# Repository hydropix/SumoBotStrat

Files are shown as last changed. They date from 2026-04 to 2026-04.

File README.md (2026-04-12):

# SumoBotStrat

Un robot sumo autonome qui se bat tout seul sur un ring ! Il detecte son adversaire, le poursuit et essaie de le pousser hors de l'arene. Toute sa strategie a ete mise au point grace a un simulateur sur ordinateur, puis transferee sur le vrai robot.

SumoBot MuJoCo simulation

## C'est quoi un robot sumo ?

Le robot sumo, c'est un sport de robots : deux robots sont poses sur un ring circulaire noir (appele "dohyo"), et chacun doit pousser l'autre en dehors. Le ring a une bordure blanche que le robot doit detecter pour ne pas tomber lui-meme.

Notre robot pese entre 500g et 1kg et fonctionne avec une carte **Arduino Mega 2560** (une sorte de mini-ordinateur programmable).

## Notre approche : simuler avant de construire

Plutot que de programmer le robot a l'aveugle et de faire des dizaines d'essais physiques (ce qui prend du temps et casse le materiel), on a choisi une approche differente :

**1. On a cree un simulateur sur ordinateur** qui reproduit fidelement le comportement du robot : ses moteurs, ses capteurs, la physique des collisions, le ring...

**2. On a fait jouer le robot virtuel des milliers de matchs** contre differents types d'adversaires pour trouver les meilleurs reglages.

**3. On a transfere la strategie gagnante sur le vrai robot.**

```text
    ORDINATEUR                                         ROBOT REEL
 ┌──────────────┐     ┌──────────────┐     ┌──────────────────────┐
 │  Simulateur  │ --> │ Optimisation │ --> │  Code Arduino final  │
 │  (virtuel)   │     │ (des milliers│     │  (memes reglages)    │
 │              │     │  de matchs)  │     │                      │
 └──────────────┘     └──────────────┘     └──────────────────────┘
```

## Le simulateur

Le simulateur est un programme qui fait "comme si" le robot existait dans l'ordinateur. Il calcule tout : comment les roues tournent, comment le robot glisse sur le sol, ce que voient les capteurs...

Vous pouvez l'essayer directement dans votre navigateur :

**[Lancer le simulateur](https://hydropix.github.io/SumoBotStrat/simulation/index.html)** (cliquez pour essayer !)

Dans le simulateur, vous verrez :
- Le ring noir avec sa bordure blanche
- Notre robot (en bleu) qui tourne, cherche, et attaque
- Un adversaire (en rouge) qu'on peut controler
- Les faisceaux laser qui detectent l'ennemi
- L'etat actuel du robot (recherche, poursuite, charge, esquive...)

### La regle d'or : pas de triche !

Le robot dans le simulateur n'a le droit d'utiliser **que** les informations qu'il aurait en vrai :
- Ses 3 capteurs laser pour "voir" l'adversaire (portee ~80 cm)
- Ses 3 capteurs de ligne pour detecter le bord du ring
- Son accelerometre/gyroscope pour sentir les chocs et sa rotation

Il n'a **pas le droit** de connaitre sa position exacte sur le ring, ni la position de l'ennemi. Comme ca, ce qui marche en simulation marchera aussi en vrai !

### Deux simulateurs complementaires

Le projet contient en fait **deux systemes de simulation** qui partagent la meme regle capteurs-uniquement :

**1. Simulateur JavaScript ([simulation/](simulation/))** — Simulation 2D legere (HTML + Canvas, zero dependance). C'est le simulateur utilise pour l'optimisation Monte Carlo massive et l'iteration rapide sur la strategie. Il tourne dans le navigateur ou en batch Node.js via [headless.js](simulation/headless.js) et [montecarlo.js](simulation/montecarlo.js).

**2. Simulateur MuJoCo ([simulation/mujoco/](simulation/mujoco/))** — Simulation physique 3D haute fidelite basee sur [MuJoCo](https://mujoco.org/) (Python). Permet de valider la strategie sur une physique rigide realiste (collisions, frottements, inertie 3D) avant le portage sur Arduino. Le GIF en haut du README montre ce simulateur en action.

Structure du simulateur MuJoCo :
- [models/](simulation/mujoco/models/) — modeles XML MuJoCo (arene, bot, ennemi, scene)
- [physics/](simulation/mujoco/physics/) — moteur de simulation et modele moteur N20
- [sensors/](simulation/mujoco/sensors/) — capteurs simules (ligne TCRT5000, laser VL53L0X, IMU MPU6050)
- [ai/](simulation/mujoco/ai/) — `bot_ai.py`, `enemy_ai.py`, parametres de strategie
- [runners/](simulation/mujoco/runners/) — `viewer.py` (interactif 3D), `headless.py` (batch), `montecarlo.py`

Installation et lancement du simulateur MuJoCo :

```bash
cd simulation/mujoco
setup.bat              # cree venv + installe mujoco, numpy
run_viewer.bat         # viewer 3D interactif
run_headless.bat       # batch de matchs headless
run_montecarlo.bat     # optimisation des parametres
```

## Comment on a trouve les meilleurs reglages : la methode Monte Carlo

Le robot a 16 reglages qu'on peut ajuster : a quelle vitesse il tourne pour chercher, a quelle vitesse il charge, a quel angle il attaque de cote, etc. Trouver la meilleure combinaison a la main serait impossible (il y a des milliards de possibilites).

On a donc utilise la **methode Monte Carlo** : c'est une technique qui consiste a essayer beaucoup de combinaisons au hasard et garder les meilleures. C'est un peu comme si vous lanciez des flechettes au hasard sur une cible, et qu'a chaque tour vous vous rapprochiez de la zone ou tombent les meilleures flechettes.

### Etape 1 — Chercher large

On genere **80 combinaisons de reglages** au hasard, et chacune joue **200 matchs** contre **12 adversaires differents** :
- Des adversaires de toutes tailles (petits, gros, legers, lourds, lents, rapides)
- Des adversaires "intelligents" qui traquent aussi notre robot

On garde les 8 meilleures combinaisons et on les reteste avec 800 matchs pour etre sur.

### Etape 2 — Affiner

Autour de la meilleure combinaison de l'etape 1, on genere **100 nouvelles combinaisons** proches (on ajuste legerement chaque reglage). On les reteste et on garde la meilleure.

### Etape 3 — Valider

On fait jouer le champion **3000 matchs** contre chaque type d'adversaire pour confirmer qu'il est vraiment bon partout.

### Resultats

| Adversaire | Victoires |
| --- | --- |
| Adversaires basiques (8 types differents) | 99.7 a 100% |
| Adversaire intelligent (standard) | 92.5% |
| Adversaire intelligent + lourd + rapide | ~47% |

Le seul adversaire problematique est un ennemi a la fois intelligent, lourd et rapide. En competition reelle, ce scenario est tres rare.

## Comment le robot "reflechit" : la machine a etats

Le robot ne "pense" pas vraiment, mais il suit des regles precises. A chaque instant, il est dans un **etat** (une situation) et reagit en fonction de ce qu'il detecte. Voici ses 8 etats :

| Etat | Ce que fait le robot | Quand ? |
| ---- | --- | --- |
| **WAIT_START** | Attend qu'on appuie sur le bouton | Au demarrage |
| **COUNTDOWN** | Attend 5 secondes (reglementaire) | Apres le bouton |
| **SEARCH** | Tourne sur lui-meme pour scanner autour | Quand il ne voit rien |
| **FLANK** | Approche en arc de cercle (~30 deg) | Ennemi detecte mais loin (> 63 cm) |
| **TRACK** | Suit l'ennemi en ajustant sa direction | Ennemi detecte a moyenne distance |
| **CHARGE** | Fonce a pleine puissance ! | Ennemi proche (< 37 cm) |
| **EVADE** | Recule et tourne | Bord du ring detecte |
| **CENTER** | Avance tout droit pour revenir au centre | Apres une esquive |

En plus, le robot reagit aux chocs grace a son accelerometre :
- **Souleve par l'adversaire** : il recule et tourne pour se degager
- **Frappe sur le cote** : il tourne vers l'attaquant pour riposter
- **Frappe de face** : il esquive lateralement

## Ce qu'on a decouvert grace a la simulation

La simulation nous a permis de tester des idees et de garder seulement ce qui marche. Voici les decouvertes les plus importantes :

- **Les capteurs laser a 30 deg, c'est mieux que 90 deg.** On a teste avec les capteurs lateraux pointes a 90 degres (sur les cotes), mais le robot perdait trop souvent la cible. A 30 degres, il a un champ de vision plus concentre vers l'avant et gagne **8% de matchs en plus**.

- **Pousser meme au bord du ring, ca marche.** Normalement le robot recule quand il detecte le bord. Mais si l'ennemi est juste devant, on le laisse continuer a pousser. Ca reduit les matchs nuls de 26% a 13%.

- **Un controleur simple est meilleur qu'un controleur complique.** On a essaye un systeme de direction plus avance (controleur PD), mais le robot oscillait dans tous les sens. Le controleur simple (P) est stable et efficace.

## Les fichiers du projet

| Dossier | Contenu |
| --- | --- |
| `simulation/` | Le simulateur (ouvrir `index.html` dans un navigateur) |
| `simulation/montecarlo_v3.js` | Le programme d'optimisation Monte Carlo |
| `sumo_strategy/` | Le code final pour l'Arduino (le "cerveau" du robot) |
| `test_moteur1/` | Programme de test pour 1 moteur |
| `test_2moteurs/` | Programme de test pour 2 moteurs |
| `test_capteur_ligne/` | Programme de test pour les capteurs de bord |
| `test_ligne_moteurs/` | Programme de test : capteurs + moteurs ensemble |
| `docs/` | Schemas electriques et [guide de montage](docs/HARDWARE.md) |

## Essayer le simulateur

Ouvrir le lien ci-dessous dans un navigateur (Chrome, Firefox, Edge...). Rien a installer !

**[Lancer le simulateur](https://hydropix.github.io/SumoBotStrat/simulation/index.html)**

## Programmer le vrai robot

1. Installer [Arduino IDE](https://www.arduino.cc/en/software) sur votre ordinateur
2. Brancher l'Arduino Mega en USB
3. Ouvrir le fichier `sumo_strategy/sumo_strategy.ino`
4. Cliquer sur la fleche "Upload" pour envoyer le code sur le robot
5. Appuyer sur le bouton START du robot pour lancer le match !

## Construire le robot

Voir le **[guide de montage complet](docs/HARDWARE.md)** pour la liste des pieces et les instructions de cablage pas-a-pas.

## Licence

Voir [LICENSE](LICENSE).

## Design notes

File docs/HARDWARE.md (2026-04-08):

# Guide de montage du robot

Ce guide explique comment assembler le robot sumo pas a pas. Chaque etape est testable individuellement : on branche, on teste, et on passe a la suite seulement quand ca marche.

## De quoi a-t-on besoin ?

### Les composants principaux

| Piece | C'est quoi ? | Combien ? |
| ----- | --- | --- |
| Arduino Mega 2560 | Le "cerveau" du robot. C'est un mini-ordinateur qu'on peut programmer | 1 |
| Sensor Shield Mega | Une carte qui se branche sur l'Arduino pour faciliter le branchement des capteurs | 1 |
| L298N | Un module qui permet a l'Arduino de controler les moteurs (l'Arduino seule n'est pas assez puissante) | 1 |
| Moteurs N20 12V 500RPM | Petits moteurs avec reducteur, ils font tourner les roues | 2 |
| Roues silicone | Roues en silicone qui accrochent bien sur le ring | 2 |
| Bille folle | Une petite roulette qui sert de 3eme point d'appui a l'arriere | 1 |
| VL53L0X | Capteurs laser qui mesurent la distance (pour "voir" l'adversaire) | 3 |
| TCRT5000 | Capteurs infrarouge qui detectent la couleur du sol (noir = ring, blanc = bord) | 3 |
| MPU6050 | Capteur qui detecte les mouvements, chocs et rotations du robot | 1 |
| Batterie NiMH 7.2V | La batterie rechargeable qui alimente tout | 1 |
| Module LM2596 | Un convertisseur qui transforme le 7.2V de la batterie en 5V pour l'Arduino | 1 |
| Bouton poussoir | Pour demarrer le match | 1 |
| Fils Dupont et connecteurs | Pour relier tous les composants entre eux | - |

### Les outils necessaires

- Un tournevis cruciforme (petit)
- Un multimetre (pour verifier les tensions)
- Arduino IDE installe sur un ordinateur (logiciel gratuit)
- Un cable USB pour brancher l'Arduino a l'ordinateur

## Vocabulaire utile

Avant de commencer, voici quelques mots qu'on va utiliser souvent :

| Mot | Signification |
| --- | --- |
| **GND** | La masse, c'est le "-" de l'alimentation. Comme le pole negatif d'une pile |
| **VCC** ou **5V** | L'alimentation positive a 5 volts |
| **Pin** | Une broche (patte metallique) sur l'Arduino ou un composant |
| **PWM** | Un signal qui permet de controler la vitesse d'un moteur (au lieu de juste "allume/eteint") |
| **I2C** | Un "langage" que les capteurs utilisent pour parler a l'Arduino a travers 2 fils (SDA et SCL) |
| **Shield** | Une carte qui s'empile sur l'Arduino pour ajouter des fonctions |
| **Serial Monitor** | Un ecran dans Arduino IDE qui affiche les messages du robot (utile pour le debug) |

## Etape 1 — L'alimentation (le courant electrique)

C'est la premiere chose a faire : s'assurer que tout est bien alimente.

### Le probleme

La batterie donne 7.2V, mais l'Arduino et les capteurs ont besoin de 5V. Si on branche 7.2V directement, on grille tout ! Il faut donc un convertisseur (le module LM2596) qui transforme le 7.2V en 5V.

### Branchement de l'alimentation

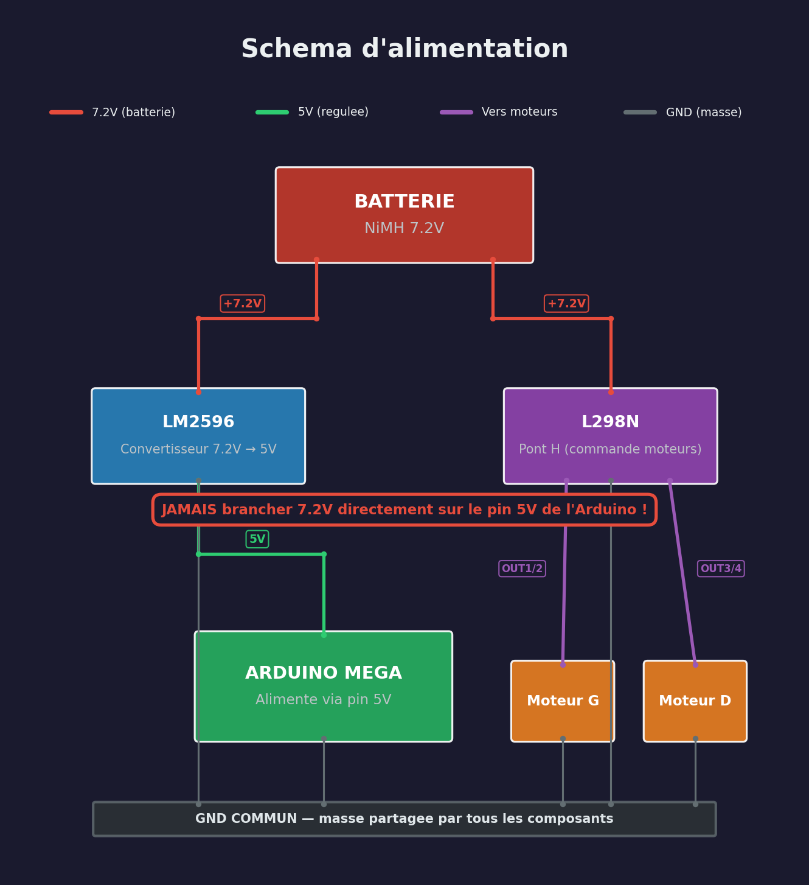
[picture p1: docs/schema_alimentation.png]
Schema d'alimentation


### Comment regler le LM2596

1. Brancher la batterie sur les bornes Vin (+) et Vin (-) du LM2596
2. **Ne rien brancher sur la sortie pour l'instant**
3. Mettre le multimetre sur la sortie (Vout + et Vout -)
4. Tourner la petite vis (potentiometre) avec un tournevis jusqu'a lire **5.0V**
5. Seulement maintenant, brancher la sortie sur le pin 5V de l'Arduino

> **ATTENTION** : Ne JAMAIS brancher la batterie 7.2V directement sur le pin 5V de l'Arduino. Ca le detruit immediatement et c'est irreversible.

### Verification

Brancher la batterie. L'Arduino doit s'allumer (une petite LED verte s'allume sur la carte). Si rien ne se passe, verifier les branchements et la tension du LM2596.

## Etape 2 — Les moteurs

Les moteurs font avancer et tourner le robot. On en utilise 2 : un a gauche et un a droite. En les faisant tourner a des vitesses differentes, le robot peut tourner.

### Le role du L298N

L'Arduino ne peut pas alimenter les moteurs directement (pas assez de puissance). Le module L298N sert d'intermediaire : l'Arduino lui envoie des ordres ("tourne a gauche, vitesse 50%"), et le L298N transmet la puissance de la batterie aux moteurs.

### Branchement des moteurs

```text
L298N                    Arduino Mega
─────                    ────────────
ENA ──────────────────── Pin 10     (vitesse moteur gauche)
IN1 ──────────────────── Pin 9      (sens moteur gauche)
IN2 ──────────────────── Pin 8      (sens moteur gauche)
IN3 ──────────────────── Pin 6      (sens moteur droit)
IN4 ──────────────────── Pin 7      (sens moteur droit)
ENB ──────────────────── Pin 5      (vitesse moteur droit)
GND ──────────────────── GND

L298N                    Moteurs
─────                    ───────
OUT1, OUT2 ──────────── Moteur GAUCHE (les 2 fils du moteur)
OUT3, OUT4 ──────────── Moteur DROIT  (les 2 fils du moteur)
```

### Le jumper 5V du L298N

Il y a un petit cavalier (jumper) sur le L298N marque "5V EN". **Il faut l'enlever.** Ce jumper active un regulateur interne qui n'est pas assez puissant pour notre robot. On utilise le LM2596 a la place.

### Si un moteur tourne a l'envers

Pas de panique ! Il suffit d'inverser les 2 fils du moteur sur le bornier du L298N (echanger OUT1 et OUT2, ou OUT3 et OUT4).

### Test

1. Brancher l'Arduino a l'ordinateur en USB
2. Ouvrir `test_moteur1/test_moteur1.ino` dans Arduino IDE
3. Cliquer sur "Upload" (fleche vers la droite)
4. Le moteur gauche doit tourner dans un sens, puis dans l'autre
5. Ensuite, tester avec `test_2moteurs/test_2moteurs.ino` : les deux moteurs tournent ensemble (avant, arriere, tourne a gauche, tourne a droite)

## Etape 3 — Les capteurs de ligne (TCRT5000)

Ces capteurs empechent le robot de tomber du ring. Ils envoient un faisceau infrarouge vers le sol et mesurent la lumiere reflechie. Le sol noir du ring reflechit peu, mais la bordure blanche reflechit beaucoup.

### Branchement des capteurs de ligne

On utilise le Shield Sensor, une carte qui se branche directement sur l'Arduino et qui offre des rangees de 3 broches (S, V, G) pour chaque pin :

- **S** = Signal (le fil de donnees du capteur)
- **V** = 5V (l'alimentation du capteur)
- **G** = GND (la masse)

```text
Shield Sensor Mega (section ANALOG)
────────────────────────────────────
Pin A0 (S/V/G) ──── TCRT5000 #1 (avant-gauche)
Pin A1 (S/V/G) ──── TCRT5000 #2 (avant-droit)
Pin A2 (S/V/G) ──── TCRT5000 #3 (arriere)
```

> **ATTENTION** : Le shield a deux zones qui se ressemblent. Les pins analogiques (A0, A1, A2...) sont d'un cote, et les pins numeriques de l'autre. Il faut brancher sur le cote **ANALOG**.

### Ou placer les capteurs sur le robot

Le placement de tous les capteurs est visible sur ce schema (vue de dessus) :

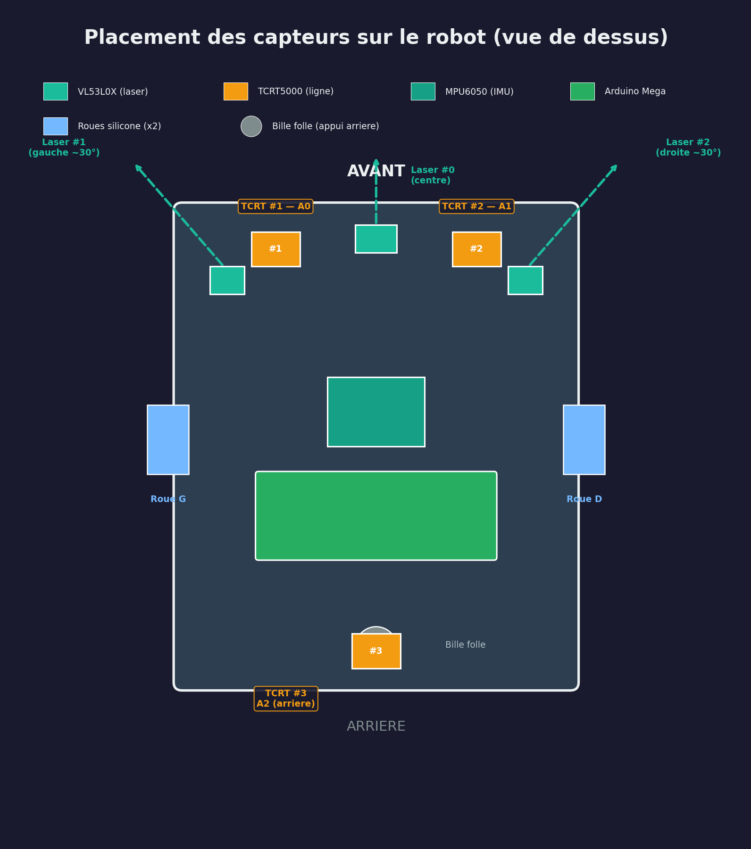
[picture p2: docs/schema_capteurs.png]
Placement des capteurs


Les 2 capteurs avant depassent du chassis vers l'avant, a 5mm du sol. Le capteur arriere est au milieu, a 5mm du sol aussi.

### Test et calibration

1. Ouvrir `test_capteur_ligne/test_capteur_ligne.ino` et l'envoyer sur l'Arduino
2. Ouvrir le Serial Monitor dans Arduino IDE (icone loupe en haut a droite, regler sur 9600 baud)
3. Presenter une feuille blanche sous le capteur : on doit voir une valeur basse (ex: 100-200)
4. Presenter une surface noire : la valeur doit etre haute (ex: 600-900)
5. Le seuil par defaut est 300. Si vos valeurs sont differentes, ajustez-le dans le code

Ensuite, tester avec `test_ligne_moteurs/test_ligne_moteurs.ino` : le robot doit avancer et reculer automatiquement quand il detecte du blanc.

## Etape 4 — Les capteurs de distance (VL53L0X)

Ce sont les "yeux" du robot. Ils envoient un faisceau laser invisible et mesurent le temps que met la lumiere a revenir, ce qui donne la distance d'un objet (ici, l'adversaire). Portee : environ 80 cm.

Le robot en utilise 3 : un qui regarde droit devant, et deux sur les cotes (a environ 30 degres). Ca lui donne un "champ de vision" de 60 degres.

### Le probleme : ils ont tous la meme adresse

Les VL53L0X communiquent avec l'Arduino par un systeme appele I2C (2 fils partages : SDA et SCL). Le probleme, c'est qu'ils ont tous la meme "adresse" par defaut. C'est comme si 3 eleves dans une classe avaient le meme prenom : quand le prof appelle, ils repondent tous en meme temps !

La solution : chaque capteur a un fil special (XSHUT) qui permet de l'allumer ou l'eteindre. Au demarrage, le code allume les capteurs un par un et donne a chacun une adresse differente.

### Branchement des lasers

```text
Les 3 VL53L0X partagent les memes fils I2C :
  VIN ──── 5V (via le shield)
  GND ──── GND
  SDA ──── Pin 20 (sur l'Arduino Mega, c'est le fil de donnees I2C)
  SCL ──── Pin 21 (c'est le fil d'horloge I2C)

Chaque capteur a son fil XSHUT individuel :
  VL53L0X #0 (centre) : XSHUT ──── Pin 22
  VL53L0X #1 (gauche) : XSHUT ──── Pin 23
  VL53L0X #2 (droite) : XSHUT ──── Pin 24
```

### Ou placer les capteurs laser

Le placement des lasers est visible sur le schema des capteurs plus haut. Le laser #0 pointe droit devant, les lasers #1 et #2 sont orientes a environ 30 degres de chaque cote.

> **Pourquoi 30 degres et pas plus ?** On a teste avec des angles de 60 et 90 degres dans le simulateur, mais le robot perdait la cible trop souvent. A 30 degres, il gagne 8% de matchs en plus !

### Test

Apres le branchement, envoyer le code principal (`sumo_strategy/sumo_strategy.ino`) et ouvrir le Serial Monitor. Au demarrage, le message "Lasers OK" doit apparaitre. Si vous voyez "ERR laser0" (ou 1 ou 2), verifier le cablage du capteur concerne.

## Etape 5 — L'accelerometre/gyroscope (MPU6050)

Ce capteur detecte les mouvements du robot : les chocs, les rotations, et meme si le robot est souleve par l'adversaire. C'est un peu comme l'oreille interne chez l'humain, qui nous donne le sens de l'equilibre.

### Branchement de l'IMU

Le MPU6050 partage les memes fils I2C que les capteurs laser (SDA et SCL), mais avec une adresse differente, donc pas de conflit.

```text
MPU6050              Arduino Mega
───────              ────────────
VCC ──────────────── 5V (via le shield)
GND ──────────────── GND
SDA ──────────────── Pin 20 (meme fil que les VL53L0X)
SCL ──────────────── Pin 21 (meme fil que les VL53L0X)
AD0 ──────────────── GND (ca fixe son adresse pour eviter les conflits)
```

### Ce que le robot en fait

| Mesure | Le robot l'utilise pour... |
| --- | --- |
| Acceleration avant/arriere | Detecter une collision frontale et esquiver sur le cote |
| Acceleration laterale | Detecter un choc sur le cote et tourner vers l'attaquant |
| Vitesse de rotation | Savoir quand il a fait un tour complet en mode recherche |

### Placement de l'IMU

Monter le MPU6050 **au centre du robot**, bien fixe. S'il vibre trop, les mesures seront fausses. Utiliser du scotch double-face epais ou de la mousse pour l'isoler des vibrations.

## Etape 6 — Le bouton de demarrage

En competition, on doit appuyer sur un bouton, puis le robot attend 5 secondes avant de commencer (c'est la regle). Ce bouton declenche le compte a rebours.

### Branchement du bouton

C'est le branchement le plus simple du projet :

```text
Bouton poussoir
  Broche 1 ──── Pin 2 de l'Arduino
  Broche 2 ──── GND
```

Pas besoin de resistance : l'Arduino a une resistance interne (pull-up) qui fait le travail.

### Comment ca marche

1. Robot allume → la LED de l'Arduino clignote **lentement** (il attend)
2. Appui sur le bouton → la LED clignote **vite** (compte a rebours de 5 secondes)
3. Fin du compte a rebours → le robot demarre et cherche l'ennemi

## Schema de cablage complet

Voici une vue d'ensemble de tous les branchements :

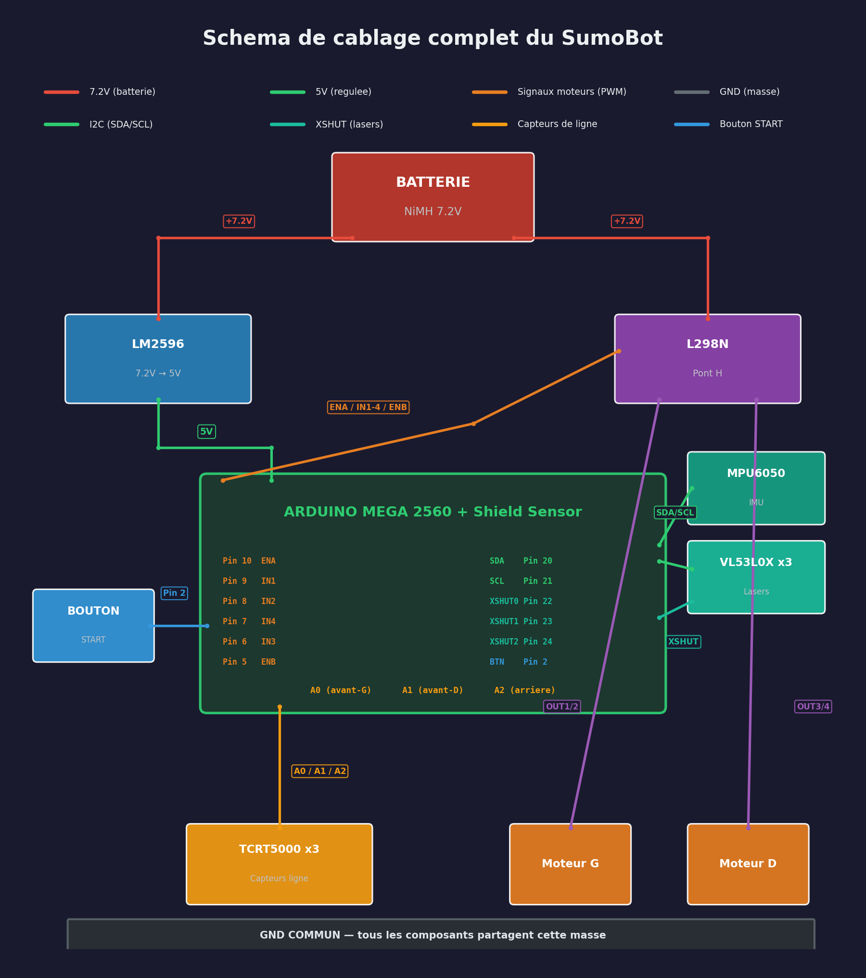
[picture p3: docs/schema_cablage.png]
Schema de cablage complet


## Tableau recapitulatif : quel fil va ou

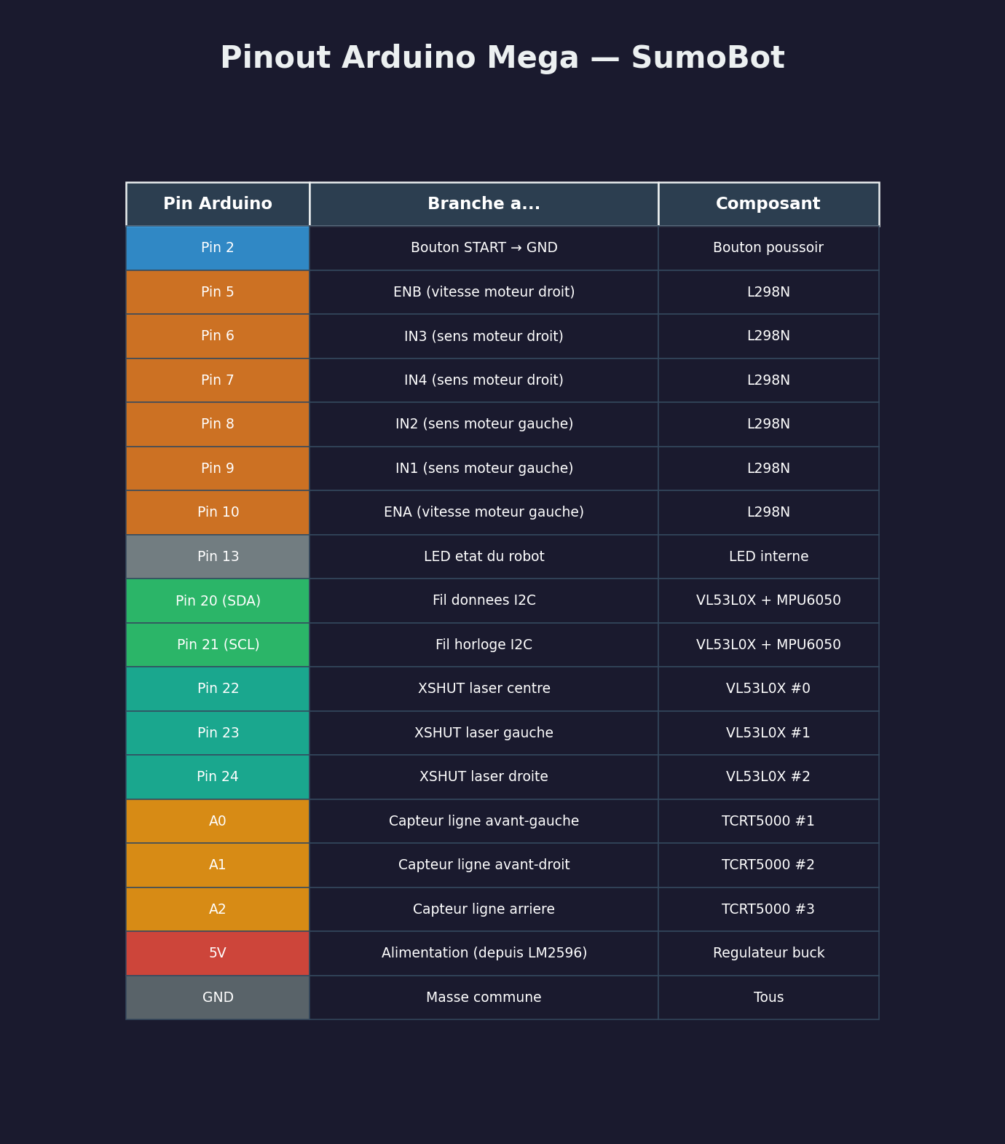
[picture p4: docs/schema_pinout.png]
Tableau du pinout


## Conseils importants

### La masse commune (GND)

C'est la cause numero 1 des problemes. **Tous les composants doivent partager le meme GND.** Si un seul GND est mal branche, les moteurs peuvent se comporter bizarrement, les capteurs peuvent donner des valeurs fausses, etc. En cas de probleme, verifier les GND en premier.

### Le poids

En competition, le robot doit peser moins de 1 kg. Voici une estimation du poids de chaque piece :

| Piece | Poids |
| ----- | ----- |
| Arduino Mega + shield | ~55g |
| L298N | ~30g |
| 2 moteurs N20 + roues | ~40g |
| Batterie NiMH 7.2V | ~150-200g |
| Chassis + lame | ~300-400g |
| Capteurs + cablage | ~50g |
| **Total** | **~625-775g** |

Il reste de la marge, mais attention au chassis : c'est souvent la piece la plus lourde.

### Les vibrations

Les capteurs laser (VL53L0X) et l'accelerometre (MPU6050) sont sensibles aux vibrations. Si le robot vibre beaucoup en roulant, les mesures seront bruitees. Utiliser de la mousse ou du scotch double-face epais entre les capteurs et le chassis.

### Les fils I2C

Le bus I2C (les fils SDA et SCL) est partage entre 4 capteurs. Pour que ca marche bien :

- Garder les fils **courts** (moins de 15 cm)
- Si les capteurs se deconnectent souvent, ajouter une resistance de 4.7 kohms entre SDA et 5V, et une autre entre SCL et 5V (certains modules les ont deja)
- Le code a un systeme de recuperation automatique si le bus se bloque

### Le watchdog

Le code du robot active un "chien de garde" (watchdog). Si le programme se bloque pendant plus de 0.5 seconde, l'Arduino redemarre automatiquement. C'est une securite pour que le robot ne reste jamais immobile en plein match.

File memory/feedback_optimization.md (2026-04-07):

---
name: Strategy Optimization Results - What Works and What Doesn't
description: Detailed log of all tested strategies and parameter changes with measured impact - prevents re-testing failed approaches
type: feedback
---

## POSITIF (garder, ne pas reverter)

### 3 lasers avant (centre + 2 lateraux en V) — IMPACT MAJEUR
- Ancien: 2 lasers a ±0.26 rad, kp=0.6 → 86.9% pondere multi-taille
- Nouveau: 3 lasers (centre droit + lateraux ±0.47 rad), kp=1.28 → **95.1% pondere** (+8.2%)
- Le laser central comble le trou entre les lateraux. Quand il detecte mais pas un lateral, sa distance + centerFill (165mm) remplace le lateral manquant.
- Avec le centre, on peut aller a ±27° sans degradation (ancien max etait ±17° sans centre).
- Robustesse multi-taille : S(35mm)=94.4%, D(55mm)=95.2%, XL(75mm)=95.3%. L'ancien s'effondrait a 78% sur XL.
- Monte Carlo v2 confirme: kp=0.6-1.3, laserAngle=0.40-0.48, centerFill=140-280 sont tous au plafond (94-95%).

### Edge-charge (ne pas EVADE sur 1 seul capteur avant pendant CHARGE) — IMPACT MAJEUR
- **+2-3% WR, timeouts /2** (de 26% a ~13%)
- Logique: si CHARGE/TRACK actif + ennemi detecte devant + 1 seul capteur avant sur la ligne → continuer a pousser avec correction de direction (edgeSteer).
- EVADE seulement si: les 2 capteurs avant sont dans le blanc, OU capteur arriere, OU pas en engagement.
- edgeSteer: 0.3/0.5/0.7 donnent des resultats quasi identiques. Le facteur cle est de NE PAS declencher EVADE.

### searchPwm=0.95 — impact modere
- +1% WR vs 0.75. Spin plus rapide = balayage plus rapide.
- 1.0 ne fait pas mieux que 0.95.

### trackPwm=0.9 — impact modere
- +1% WR vs 0.8. Ferme la distance plus vite.
- 0.95 est trop agressif (leger recul).

### evadePwm=0.85 — impact leger
- Reduit timeouts de ~2%. Evade plus rapide = retour au combat plus vite.

## NEGATIF (ne PAS re-tester)

### Capteurs lateraux a 90° — TOUJOURS NEGATIF
Teste sous 5 formes differentes, toutes pires que baseline:
1. **PIVOT state (spin pur vers detection laterale)** : 78.2% WR. Le bot oscille entre PIVOT et SEARCH.
2. **Direction hint continu** : 79.7% WR. Les lateraux detectent presque toujours (800mm portee, arene 385mm rayon) → flip-flop constant.
3. **Single-shot hint (1ere frame seulement)** : 88.2% WR. Neutre vs baseline.
4. **Close-range acquire (<250mm)** : 80.9% WR. ACQUIRE bloquant.
5. **Curved flank approach** : 83.4% WR. Toujours du drift parasite.
**Why:** Dans une arene de 77cm, le temps de rotation 90° pour face-to-face est trop long — l'ennemi bouge pendant le pivot. La portee 800mm cause des detections perpetuelles.

### Arc search (forward + spin au centre) — NEGATIF
- Derive hors portee laser. Le bot s'eloigne de la zone optimale.
- Teste avec fwdBias de 0.2 et 0.3: toujours pire.

### PD controller (ajout de kd) — CATASTROPHIQUE
- Amplifie le bruit laser → instabilite totale.

### Last-known direction search — NEUTRE
- La direction est perimee apres EVADE (le heading change). 89.6% vs 89.1% baseline = bruit statistique.

### Search direction reversal (inverser tous les 2-2.5s) — NEGATIF
- Empeche de completer un sweep complet. Combiné avec d'autres: toujours pire.

### Progressive speed ramp — NEUTRE/NEGATIF
- Perte tracking a mi-distance.

### chargePwm < 1.0 — TOUJOURS NEGATIF
- Force brute > precision en charge.

### chargeThreshold=300 — NEUTRE
- 88.4% vs 89.1% baseline. Pas de gain significatif.

### evade times plus courts (0.35/0.25) — NEGATIF
- 88.3% WR. Le bot ne recule pas assez loin du bord.

## Monte Carlo (150 configs, revalidation top 10 a 3000 rounds)
- Confirme que la config manuelle (kp=0.6, searchPwm=0.95, trackPwm=0.9, evadePwm=0.85, laserAngle=0.26) est au plafond.
- Aucune config random n'a battu le manual a 5000 rounds.
- Les parametres sont robustes: des configs tres differentes (kp 0.33-0.97) donnent toutes 93-95%.
- **Conclusion: c'est l'algo (edge-charge, laser V) qui drive la performance, pas le fine-tuning.**

**How to apply:** Avant de tester un changement, verifier ici qu'il n'a pas deja ete teste. Pour aller au-dela de 95%, il faut un changement structurel (nouveau capteur, nouvelle logique), pas du tuning.

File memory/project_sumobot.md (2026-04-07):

---
name: SumoBot Hardware Config & Progress
description: Arduino Mega sumo bot - hardware, wiring, pin assignments, build phases, simulation and current progress
type: project
---

Projet de robot sumo sur Arduino Mega 2560.

## Hardware

- Moteurs: N20 12V 500RPM x2 (alimentes a 7.5V via batterie)
- Driver: L298N (jumper auto-alimentation active)
- Batterie: NiMH 7.5V
- Masse cible: ~500g
- Capteurs ligne: TCRT5000 x3 (2 avant coins + 1 arriere centre)
- Capteurs distance: VL53L0X x4 disponibles, 3 montes a l'avant (1 centre droit + 2 lateraux ±27°), 1 en spare
- IMU: MPU6050 (prevu, pas encore monte). Adresse I2C 0x68, partage bus avec VL53L0X. INT sur pin 2 ou 3.
- Buck converter: LM2596 (7.5V -> 5V)
- Shield sensor Mega (rangees S/V/G par pin)

## Pin Assignments

- ENA (PWM) -> Pin 10, IN1 -> Pin 9, IN2 -> Pin 8 (moteur gauche)
- ENB (PWM) -> Pin 5, IN3 -> Pin 6, IN4 -> Pin 7 (moteur droit)
- TCRT5000 #1 -> A0, #2 -> A1, #3 -> A2
- VL53L0X: SDA -> Pin 20, SCL -> Pin 21, XSHUT -> Pins 22, 23, 24
- MPU6050: SDA -> Pin 20, SCL -> Pin 21 (partage I2C), INT -> Pin 2

## Alimentation

- 7.5V direct -> L298N VCC -> moteurs (jumper auto-alim)
- 7.5V -> Buck -> 5V -> Arduino pin 5V (PAS VIN), capteurs, lasers
- GND commun partout

## Simulation — Ce que le systeme modelise

### Fichiers

- simulation/index.html : simulateur visuel (HTML + JS Canvas, zero dependance)
- simulation/headless.js : simulateur headless Node.js pour tests massifs
- simulation/montecarlo.js : optimisation Monte Carlo v1 (2 lasers, obsolete)
- simulation/montecarlo_v2.js : Monte Carlo v2, multi-profil ennemi (taille/masse/vitesse)

### Physique (identique headless et html)

- **Moteurs N20** : modele force-vitesse lineaire, couple stall 0.025 N.m, 312 RPM a vide a 7.5V
- **Traction per-wheel** : mu=0.6, chaque roue a sa propre limite de traction. Stall force 1.63N > traction 1.47N = patinage a plein regime
- **Masse/vitesse per-robot** : chaque robot a ses propres mass, inertia, stallForce, noLoadSpeed, tractionMax
- **Collision** : impulsions avec restitution 0.15, masses individuelles
- **Tilt per-wheel (soulevement directionnel)** :
  - Continu tant que l'attaquant pousse (base sur vitesse de fermeture + force moteur, pas juste l'impact)
  - Direction: cote = souleve la roue du cote impacte. Arriere = les 2 roues. Face a face = pas de tilt (lames s'opposent)
  - Effet: traction de la roue soulevee chute (x1.8 par rad de tilt), la roue au sol garde sa traction → le bot pivote
  - Decay: 3.0 rad/s (~0.23s pour retomber completement)
  - Perspective visuelle: cote souleve = plus grand (plus proche camera), cote au sol = plus petit, trapeze
- **Friction laterale** : forte (30 s⁻¹), empeche le derapage lateral. Reduite par le tilt.
- **Sub-stepping** : physique a 240Hz, IA a 60Hz

### Capteurs simules

- **3x VL53L0X avant** : 1 centre (0°) + 2 lateraux (±27°). Raycasting sur le cercle de collision ennemi. Portee 800mm.
- **centerFill** : si centre detecte mais pas un lateral, d0 + 165mm remplace le lateral manquant.
- **3x TCRT5000 ligne** : detection du bord blanc (2 avant coins, 1 arriere centre)
- **IMU (MPU6050) simule** :
  - Accelerometre (ax, ay) : calcule depuis delta vitesse dans le referentiel robot, en m/s²
  - Gyroscope (gz) : omega du robot en rad/s. Heading cumule par integration.
  - Tilt : lu depuis tiltL/tiltR du modele physique

### Ennemi

- **Basic** : 5 comportements aleatoires (WANDER, ORBIT, AGGRESSIVE, DODGE, ZIGZAG) a 85% PWM
- **Smart** (--smart / touche S) : omniscient, 8 tactiques (FLANK, MATADOR, RUSH, SHADOW, EDGE_TRAP, JUKE, BULL, EXPLOIT_EVADE). Scoring pondere + 30% randomness. Realisme humain: bruit steering ±6°, vitesse 82-100%, 12% hesitation.
- **Taille variable** (touche V) : taille 35-75mm, masse 0.3-0.8kg, vitesse 70-130% randomises a chaque round
- L'ennemi subit aussi le tilt (il peut etre souleve par le bot)

### IA du bot — Machine a etats

SEARCH → TRACK → CHARGE (+ EVADE prioritaire sauf edge-charge)
Apres EVADE → CENTER (retour centre 0.35s) → SEARCH
Etats IMU: TILT_ESC (recul si tilt >14°), IMPACT (spin vers source si choc lateral >1.5g)
Heading search: apres 360° de spin sans detection, deplacement vers le centre

### Config actuelle

```text
kp=1.0  laserAngle=0.47  centerFill=165  searchPwm=0.954
trackPwm=1.0  evadePwm=1.0  edgeSteer=0.245  chargeThreshold=300
centerReturnTime=0.35
```

## Resultats

- **91.2% pondere multi-profil** vs basic (3000 rounds, 8 profils taille/masse/vitesse)
- **74.6%** vs smart enemy avec IMU+tilt (+1.8% vs sans IMU)
- Pertes FLANK reduites de 18% grace a IMU (detection impact lateral)
- Contre ennemi 0.8kg+130% vitesse (~2x momentum): WR plafonne a ~67% (limite physique)

## Faiblesses restantes

1. **EDGE_TRAP (~60% des pertes vs smart)**: ennemi entre bot et centre, gagne au timeout
2. **Attaques hors-cone (~30%)**: RUSH/FLANK depuis angles morts, partiellement resolu par IMU
3. Pas de capteur arriere (VL53L0X spare disponible)
4. Pas de capteurs ligne lateraux

### Pistes d'amelioration

- VL53L0X arriere (spare dispo, cout 0) → elimine angle mort arriere
- 2x TCRT5000 lateraux → survie edge-trap
- Ne pas charger quand heading pointe vers l'exterieur pres du bord
- Mode "hold center" si match > 15s
- 2x IR LED+phototransistor flancs (detection laterale rapide)

## Progression (2026-04-07)

- Phase 0-2: OK - Alimentation, Arduino, moteurs testes
- Phase 3: EN COURS - capteurs ligne et distance
- Phase 4: A faire - integration strategie sumo sur Arduino
- Simulation visuelle + headless: DONE
- Monte Carlo v1 + v2: DONE
- 3e laser central: DONE
- Tilt per-wheel + IMU simule: DONE
- Physique per-robot (masse/vitesse/taille variable): DONE
- Smart enemy: DONE
- CENTER_RETURN: DONE

**Why:** Projet personnel de competition sumo bot, categorie 500g-1kg.
**How to apply:** Utiliser smart enemy + taille variable pour guider les ameliorations capteurs/algo, puis porter sur Arduino.

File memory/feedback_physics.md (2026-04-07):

---
name: Simulation physics integrity
description: Simulation must use honest sensor-only AI and real physics - no omniscient shortcuts
type: feedback
---

Le bot ne doit utiliser QUE les donnees de ses capteurs (lasers VL53L0X en mm, TCRT5000 ligne). Pas de triche avec atan2 vers l'ennemi ou acces direct a la position adverse.

**Why:** Bruno a detecte que le mode SEARCH utilisait atan2(ene.y - bot.y, ...) pour s'orienter — ce n'est pas realiste. Un vrai robot tourne a l'aveugle jusqu'a ce qu'un laser detecte quelque chose.

**How to apply:** En mode SEARCH, rotation a vitesse fixe (spin aveugle). Toute logique de centrage/tracking doit passer par les lectures laser d1/d2. Les VL53L0X donnent des distances en mm — utiliser cette unite dans l'IA.

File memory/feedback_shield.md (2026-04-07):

---
name: Shield Sensor Mega
description: User uses a Mega sensor shield - connect via S/V/G rows, analog pins for TCRT5000
type: feedback
---

Bruno utilise un shield sensor pour le Mega. Les capteurs se branchent sur les rangées S (signal) / V (VCC) / G (GND) du shield.

**Why:** Simplifie le câblage, pas besoin de breadboard ni fils Dupont séparés pour VCC/GND.
**How to apply:** Toujours indiquer la rangée du shield (ex: "rangée A0 du shield") plutôt que des branchements fils individuels.

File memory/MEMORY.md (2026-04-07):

- [SumoBot Config & Progress](project_sumobot.md) — Hardware, simulation, strategie IA optimisee (95.2% WR), prochaine etape: porter sur Arduino
- [Bruno Profile](user_bruno.md) — Builder profile, French speaker, methodical hardware approach
- [Shield Sensor](feedback_shield.md) — Uses Mega sensor shield, connect via S/V/G rows
- [Physics Model](feedback_physics.md) — Simulation must use real SI physics, no cheating (atan2 toward enemy), blind search only
- [Optimization Results](feedback_optimization.md) — Detailed log of ALL tested strategies: what works (laser V, edge-charge) and what fails (side sensors, arc search, PD, etc.)

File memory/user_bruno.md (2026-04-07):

---
name: Bruno - Sumo Bot Builder
description: User building an Arduino Mega sumo bot, hardware-focused with progressive build approach
type: user
---

Bruno construit un robot sumo Arduino Mega. Approche méthodique et progressive (phase par phase). Documentation détaillée de son hardware et câblage. Communication en français.

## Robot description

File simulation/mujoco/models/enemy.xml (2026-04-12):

<mujoco model="enemy">
  <!--
    Enemy robot: same dimensions as sumobot by default.
    Configurable mass, size, speed via scene assembly.
  -->

  <default>
    <joint damping="0.0001" armature="0.00001"/>
    <geom condim="4" solimp="0.95 0.99 0.001" solref="0.004 1"/>
  </default>

  <asset>
    <material name="enemy_red" rgba="0.75 0.2 0.2 1"/>
    <material name="enemy_wedge" rgba="0.6 0.15 0.15 1"/>
    <material name="enemy_wheel" rgba="0.15 0.15 0.15 1"/>
  </asset>

  <worldbody>
    <body name="ene_chassis" pos="0 0 0.065">
      <freejoint name="ene_root"/>

      <inertial pos="-0.005 0 -0.003" mass="0.47" diaginertia="0.000396 0.000396 0.000784"/>

      <geom name="ene_body" type="box" size="0.05 0.05 0.0125" material="enemy_red" friction="0.4 0.005 0.001" mass="0"/>


      <geom name="ene_skid" type="sphere" size="0.005" pos="-0.045 0 -0.0125" friction="0.2 0.001 0.001" mass="0.005"/>

      <!-- Sensor sites -->
      <site name="ene_laser_center" pos="0.05 0 0" size="0.003"/>
      <site name="ene_laser_left" pos="0.05 -0.025 0" euler="0 0 -0.526" size="0.003"/>
      <site name="ene_laser_right" pos="0.05 0.025 0" euler="0 0 0.526" size="0.003"/>
      <site name="ene_line_fl" pos="0.047 -0.045 -0.0125" size="0.004"/>
      <site name="ene_line_fr" pos="0.047 0.045 -0.0125" size="0.004"/>
      <site name="ene_line_r" pos="-0.047 0 -0.0125" size="0.004"/>
      <site name="ene_imu" pos="0 0 0" size="0.002"/>

      <body name="ene_wheel_L" pos="0 -0.04 -0.003">
        <joint name="ene_wheel_L_joint" type="hinge" axis="0 1 0"/>
        <geom name="ene_wheel_L_geom" type="cylinder" size="0.015 0.005" euler="90 0 0" material="enemy_wheel" friction="0.6 0.008 0.002" mass="0.008" condim="4"/>
      </body>

      <body name="ene_wheel_R" pos="0 0.04 -0.003">
        <joint name="ene_wheel_R_joint" type="hinge" axis="0 1 0"/>
        <geom name="ene_wheel_R_geom" type="cylinder" size="0.015 0.005" euler="90 0 0" material="enemy_wheel" friction="0.6 0.008 0.002" mass="0.008" condim="4"/>
      </body>
    </body>
  </worldbody>

  <actuator>
    <motor name="ene_motor_L" joint="ene_wheel_L_joint" ctrlrange="-0.05 0.05" ctrllimited="true"/>
    <motor name="ene_motor_R" joint="ene_wheel_R_joint" ctrlrange="-0.05 0.05" ctrllimited="true"/>
  </actuator>

  <sensor>
    <accelerometer name="ene_accel" site="ene_imu"/>
    <gyro name="ene_gyro" site="ene_imu"/>
  </sensor>
</mujoco>

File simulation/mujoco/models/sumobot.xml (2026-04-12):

<mujoco model="sumobot">
  <!--
    SumoBot robot: 10x10cm chassis, 500g total, N20 motors, differential drive.
    Coordinate frame: X=forward, Y=left, Z=up.
    Chassis bottom at z=0.065 (arena top=0.05, wheel radius=0.015).
  -->

  <default>
    <joint damping="0.0001" armature="0.00001"/>
    <geom condim="4" solimp="0.95 0.99 0.001" solref="0.004 1"/>
  </default>

  <asset>
    <material name="chassis_blue" rgba="0.2 0.35 0.75 1"/>
    <material name="wedge_yellow" rgba="0.85 0.78 0.15 1"/>
    <material name="wheel_black" rgba="0.1 0.1 0.1 1"/>
  </asset>

  <worldbody>
    <body name="bot_chassis" pos="0 0 0.065">
      <freejoint name="bot_root"/>

      <!-- Chassis inertial: CoG slightly rear and low (battery placement) -->
      <inertial pos="-0.008 0 -0.004" mass="0.47" diaginertia="0.000396 0.000396 0.000784"/>

      <!-- Main body: 10x10x2.5cm box -->
      <geom name="bot_body" type="box" size="0.05 0.05 0.0125" material="chassis_blue" friction="0.4 0.005 0.001" mass="0"/>

      <!-- Front wedge: angled blade for getting under opponent -->
      <geom name="bot_wedge" type="box" size="0.018 0.048 0.001" pos="0.052 0 -0.011" euler="0 0.224 0" material="wedge_yellow" friction="0.3 0.003 0.001" mass="0.01"/>

      <!-- Rear skid (prevents tipping backward) -->
      <geom name="bot_skid" type="sphere" size="0.005" pos="-0.045 0 -0.0125" friction="0.2 0.001 0.001" mass="0.005"/>

      <!-- ===== SENSOR SITES ===== -->
      <!-- Laser origins (front face) -->
      <site name="bot_laser_center" pos="0.05 0 0" euler="0 0 0" size="0.003"/>
      <site name="bot_laser_left" pos="0.05 -0.025 0" euler="0 0 -0.526" size="0.003"/>
      <site name="bot_laser_right" pos="0.05 0.025 0" euler="0 0 0.526" size="0.003"/>

      <!-- Line sensor positions (bottom face) -->
      <site name="bot_line_fl" pos="0.047 -0.045 -0.0125" size="0.004" rgba="1 0 0 0.5"/>
      <site name="bot_line_fr" pos="0.047 0.045 -0.0125" size="0.004" rgba="1 0 0 0.5"/>
      <site name="bot_line_r" pos="-0.047 0 -0.0125" size="0.004" rgba="0 1 0 0.5"/>

      <!-- IMU site (center of chassis) -->
      <site name="bot_imu" pos="0 0 0" size="0.002"/>

      <!-- ===== WHEELS ===== -->
      <!-- Left wheel (Y-negative side) -->
      <body name="bot_wheel_L" pos="0 -0.04 -0.003">
        <joint name="bot_wheel_L_joint" type="hinge" axis="0 1 0"/>
        <geom name="bot_wheel_L_geom" type="cylinder" size="0.015 0.005" euler="90 0 0" material="wheel_black" friction="0.6 0.008 0.002" mass="0.008" condim="4"/>
      </body>

      <!-- Right wheel (Y-positive side) -->
      <body name="bot_wheel_R" pos="0 0.04 -0.003">
        <joint name="bot_wheel_R_joint" type="hinge" axis="0 1 0"/>
        <geom name="bot_wheel_R_geom" type="cylinder" size="0.015 0.005" euler="90 0 0" material="wheel_black" friction="0.6 0.008 0.002" mass="0.008" condim="4"/>
      </body>
    </body>
  </worldbody>

  <!-- Actuators: torque-controlled motors -->
  <actuator>
    <motor name="bot_motor_L" joint="bot_wheel_L_joint" ctrlrange="-0.05 0.05" ctrllimited="true"/>
    <motor name="bot_motor_R" joint="bot_wheel_R_joint" ctrlrange="-0.05 0.05" ctrllimited="true"/>
  </actuator>

  <!-- Sensors -->
  <sensor>
    <accelerometer name="bot_accel" site="bot_imu"/>
    <gyro name="bot_gyro" site="bot_imu"/>
  </sensor>
</mujoco>

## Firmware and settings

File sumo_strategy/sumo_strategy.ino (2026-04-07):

// =============================================================
// SumoBot Strategy — Arduino Mega 2560
// Port de la simulation optimisee (94.6% WR vs smart enemy)
// Machine a etats: SEARCH -> TRACK -> CHARGE -> EVADE -> CENTER
// =============================================================

#include <Wire.h>
#include <VL53L0X.h>
#include <avr/wdt.h>

// ===================== PINOUT =====================
// Moteur gauche (L298N)
#define ENA 10
#define IN1 9
#define IN2 8
// Moteur droit (L298N)
#define ENB 5
#define IN3 6
#define IN4 7
// Capteurs ligne TCRT5000
#define LINE_FL A0  // avant-gauche
#define LINE_FR A1  // avant-droit
#define LINE_R  A2  // arriere
// VL53L0X XSHUT
#define XSHUT_0 22  // centre
#define XSHUT_1 23  // gauche
#define XSHUT_2 24  // droite
// Interface
#define BTN_START 2  // bouton start (pull-up interne, GND pour demarrer)
#define LED_STATE 13 // LED onboard pour etat

// ===================== HARDWARE CONFIG =====================
#define SEUIL_BLANC 300       // a calibrer sur ring reel
#define LASER_RANGE 760       // mm (95% de portee max)
#define COUNTDOWN_MS 5000     // 5s reglementaire
#define MOTOR_DEADBAND 25     // PWM minimum pour que le moteur tourne
#define PWM_RAMP_STEP 30      // increment max par cycle (~60Hz = ~5ms/step)
#define BRAKE_MS 3            // freinage actif avant inversion de sens
#define LOOP_PERIOD_US 16667  // ~60Hz (16.67ms)

// ===================== STRATEGIE (simulation optimisee) =====================
const float KP            = 0.582;
const float SEARCH_PWM    = 0.899;
const float TRACK_PWM     = 0.99;
const float CHARGE_PWM    = 0.976;
const int   CHARGE_THRESH = 372;    // mm
const int   EVADE_FRONT_MS = 450;
const int   EVADE_REAR_MS  = 300;
const float EVADE_REV_RATIO = 0.45;
const float EVADE_PWM     = 0.964;
const float EDGE_STEER    = 0.453;
const int   CENTER_RETURN_MS = 350;
const int   CENTER_FILL   = 145;    // mm
const float FLANK_ANGLE   = 0.51;
const int   FLANK_THRESH  = 636;    // mm
const float FLANK_PWM     = 0.658;

// ===================== CAPTEURS VL53L0X =====================
VL53L0X laser0, laser1, laser2;
bool lasersOK = false;

// ===================== FILTRAGE CAPTEURS =====================
// Filtre median 3 echantillons pour lasers (elimine les outliers)
int laserBuf0[3], laserBuf1[3], laserBuf2[3];
byte laserIdx = 0;

int median3(int a, int b, int c) {
  if (a > b) { int t = a; a = b; b = t; }
  if (b > c) { int t = b; b = c; c = t; }
  if (a > b) { int t = a; a = b; b = t; }
  return b;
}

// Ligne: multi-sample pour reduire le bruit
bool readLinePin(int pin) {
  int sum = analogRead(pin) + analogRead(pin);
  return (sum / 2) < SEUIL_BLANC;
}

// ===================== ETAT IA =====================
enum State { WAIT_START, COUNTDOWN, SEARCH, TRACK, CHARGE, FLANK, EVADE, CENTER };
State aiState = WAIT_START;

// Evade
unsigned long evadeStart = 0;
int evadeDuration = 0;
int evadeDir = 1;
bool evadeRear = false;

// Center return
unsigned long centerStart = 0;

// Flank
int flankDir = 0;

// Countdown
unsigned long countdownStart = 0;

// Capteurs (valeurs filtrees)
int d0mm, d1mm, d2mm;
bool det0, det1, det2;
bool lineFL, lineFR, lineR;

// ===================== MOTEURS AVEC RAMPE =====================
int curPwmL = 0, curPwmR = 0;    // PWM actuel (-255..255)
int tgtPwmL = 0, tgtPwmR = 0;    // PWM cible

int rampToward(int current, int target, int step) {
  if (current < target) return min(current + step, target);
  if (current > target) return max(current - step, target);
  return current;
}

void applyMotor(int pwm, int pinEN, int pinA, int pinB) {
  // Deadband: en dessous du seuil, freiner plutot que chauffer
  if (abs(pwm) < MOTOR_DEADBAND) {
    digitalWrite(pinA, LOW);
    digitalWrite(pinB, LOW);
    analogWrite(pinEN, 0);
    return;
  }
  if (pwm > 0) {
    digitalWrite(pinA, HIGH); digitalWrite(pinB, LOW);
  } else {
    digitalWrite(pinA, LOW);  digitalWrite(pinB, HIGH);
  }
  analogWrite(pinEN, abs(pwm));
}

void updateMotors() {
  // Freinage actif si inversion de sens demandee
  if ((curPwmL > MOTOR_DEADBAND && tgtPwmL < -MOTOR_DEADBAND) ||
      (curPwmL < -MOTOR_DEADBAND && tgtPwmL > MOTOR_DEADBAND)) {
    // Brake: les deux pins HIGH pendant quelques ms
    digitalWrite(IN1, HIGH); digitalWrite(IN2, HIGH);
    analogWrite(ENA, 255);
    curPwmL = 0;
  }
  if ((curPwmR > MOTOR_DEADBAND && tgtPwmR < -MOTOR_DEADBAND) ||
      (curPwmR < -MOTOR_DEADBAND && tgtPwmR > MOTOR_DEADBAND)) {
    digitalWrite(IN3, HIGH); digitalWrite(IN4, HIGH);
    analogWrite(ENB, 255);
    curPwmR = 0;
  }

  // Rampe progressive
  curPwmL = rampToward(curPwmL, tgtPwmL, PWM_RAMP_STEP);
  curPwmR = rampToward(curPwmR, tgtPwmR, PWM_RAMP_STEP);

  applyMotor(curPwmL, ENA, IN1, IN2);
  applyMotor(curPwmR, ENB, IN3, IN4);
}

void setMotors(int left, int right) {
  tgtPwmL = constrain(left, -255, 255);
  tgtPwmR = constrain(right, -255, 255);
}

void stopMotors() {
  tgtPwmL = 0; tgtPwmR = 0;
  curPwmL = 0; curPwmR = 0;
  digitalWrite(IN1, LOW); digitalWrite(IN2, LOW);
  digitalWrite(IN3, LOW); digitalWrite(IN4, LOW);
  analogWrite(ENA, 0); analogWrite(ENB, 0);
}

void brakeMotors() {
  // Freinage actif (court-circuit moteur via H-bridge)
  digitalWrite(IN1, HIGH); digitalWrite(IN2, HIGH); analogWrite(ENA, 255);
  digitalWrite(IN3, HIGH); digitalWrite(IN4, HIGH); analogWrite(ENB, 255);
  curPwmL = 0; curPwmR = 0;
  tgtPwmL = 0; tgtPwmR = 0;
}

// ===================== I2C RECOVERY =====================
void i2cRecover() {
  // Si le bus I2C est bloque (SDA stuck LOW), generer des clocks manuellement
  Wire.end();
  pinMode(21, OUTPUT); // SCL
  for (int i = 0; i < 16; i++) {
    digitalWrite(21, HIGH); delayMicroseconds(5);
    digitalWrite(21, LOW);  delayMicroseconds(5);
  }
  digitalWrite(21, HIGH);
  Wire.begin();
  Wire.setClock(400000);
}

// ===================== INIT LASERS =====================
void initLasers() {
  pinMode(XSHUT_0, OUTPUT); digitalWrite(XSHUT_0, LOW);
  pinMode(XSHUT_1, OUTPUT); digitalWrite(XSHUT_1, LOW);
  pinMode(XSHUT_2, OUTPUT); digitalWrite(XSHUT_2, LOW);
  delay(10);

  // Init sequentielle avec adresses uniques
  digitalWrite(XSHUT_0, HIGH); delay(10);
  laser0.setTimeout(200);
  if (!laser0.init()) { Serial.println("ERR laser0"); return; }
  laser0.setAddress(0x30);
  laser0.setMeasurementTimingBudget(20000); // 20ms — rapide
  laser0.startContinuous(0);

  digitalWrite(XSHUT_1, HIGH); delay(10);
  laser1.setTimeout(200);
  if (!laser1.init()) { Serial.println("ERR laser1"); return; }
  laser1.setAddress(0x31);
  laser1.setMeasurementTimingBudget(20000);
  laser1.startContinuous(0);

  digitalWrite(XSHUT_2, HIGH); delay(10);
  laser2.setTimeout(200);
  if (!laser2.init()) { Serial.println("ERR laser2"); return; }
  laser2.setAddress(0x32);
  laser2.setMeasurementTimingBudget(20000);
  laser2.startContinuous(0);

  lasersOK = true;
  Serial.println("Lasers OK");
}

// ===================== LECTURE CAPTEURS =====================
void readSensors() {
  // Ligne (double lecture pour filtrage)
  lineFL = readLinePin(LINE_FL);
  lineFR = readLinePin(LINE_FR);
  lineR  = readLinePin(LINE_R);

  if (!lasersOK) {
    d0mm = d1mm = d2mm = LASER_RANGE;
    det0 = det1 = det2 = false;
    return;
  }

  // Lasers: lecture brute dans buffer circulaire
  int r0 = laser0.readRangeContinuousMillimeters();
  int r1 = laser1.readRangeContinuousMillimeters();
  int r2 = laser2.readRangeContinuousMillimeters();

  // Timeout → portee max
  if (r0 > 8000 || laser0.timeoutOccurred()) r0 = LASER_RANGE;
  if (r1 > 8000 || laser1.timeoutOccurred()) r1 = LASER_RANGE;
  if (r2 > 8000 || laser2.timeoutOccurred()) r2 = LASER_RANGE;

  // Detecter I2C bloque (les 3 en timeout simultanement)
  if (laser0.timeoutOccurred() && laser1.timeoutOccurred() && laser2.timeoutOccurred()) {
    i2cRecover();
    initLasers();
  }

  // Buffer median
  laserBuf0[laserIdx] = r0;
  laserBuf1[laserIdx] = r1;
  laserBuf2[laserIdx] = r2;
  laserIdx = (laserIdx + 1) % 3;

  // Filtre median 3 points
  d0mm = median3(laserBuf0[0], laserBuf0[1], laserBuf0[2]);
  d1mm = median3(laserBuf1[0], laserBuf1[1], laserBuf1[2]);
  d2mm = median3(laserBuf2[0], laserBuf2[1], laserBuf2[2]);

  det0 = d0mm < LASER_RANGE;
  det1 = d1mm < LASER_RANGE;
  det2 = d2mm < LASER_RANGE;
}

// ===================== LED ETAT =====================
void updateLED() {
  switch (aiState) {
    case WAIT_START: digitalWrite(LED_STATE, (millis() / 500) % 2);  break; // blink lent
    case COUNTDOWN:  digitalWrite(LED_STATE, (millis() / 100) % 2);  break; // blink rapide
    case SEARCH:     digitalWrite(LED_STATE, LOW);   break;
    case EVADE:      digitalWrite(LED_STATE, HIGH);  break;
    default:         digitalWrite(LED_STATE, HIGH);  break; // engage = allumee
  }
}

// ===================== STRATEGIE =====================
void botAI() {
  const int maxPwm = 255;
  bool anyLaser = det0 || det1 || det2;
  unsigned long now = millis();

  int eff1 = det1 ? d1mm : (det0 ? d0mm + CENTER_FILL : LASER_RANGE);
  int eff2 = det2 ? d2mm : (det0 ? d0mm + CENTER_FILL : LASER_RANGE);

  // ========== EVADE ==========
  if (aiState == EVADE) {
    unsigned long elapsed = now - evadeStart;
    if ((int)elapsed >= evadeDuration) {
      aiState = CENTER;
      centerStart = now;
      return;
    }
    if (evadeRear) {
      int spd = maxPwm * EVADE_PWM;
      setMotors(spd, spd);
    } else {
      int revMs = evadeDuration * EVADE_REV_RATIO;
      if ((int)elapsed < revMs) {
        int spd = maxPwm * EVADE_PWM;
        setMotors(-spd, -spd);
      } else {
        int spd = maxPwm * 0.8;
        setMotors(evadeDir * spd, -evadeDir * spd);
      }
    }
    return;
  }

  // ========== CENTER RETURN ==========
  if (aiState == CENTER) {
    if ((int)(now - centerStart) >= CENTER_RETURN_MS) {
      aiState = SEARCH;
      return;
    }
    if (!lineFL && !lineFR && !lineR && !det0 && !det1 && !det2) {
      int spd = maxPwm * 0.7;
      setMotors(spd, spd);
      return;
    }
    aiState = SEARCH;
  }

  // ========== LIGNE ==========
  if (lineFL || lineFR || lineR) {
    bool fwdDet = det0 || det1 || det2;
    bool engaging = fwdDet && (aiState == CHARGE || aiState == TRACK);
    bool singleFront = (lineFL || lineFR) && !(lineFL && lineFR) && !lineR;

    if (engaging && singleFront) {
      int minD = 9999;
      if (det0 && d0mm < minD) minD = d0mm;
      if (det1 && d1mm < minD) minD = d1mm;
      if (det2 && d2mm < minD) minD = d2mm;

      float err = eff1 - eff2;
      float cor = KP * err;
      int base = (minD < CHARGE_THRESH) ? maxPwm * CHARGE_PWM : maxPwm * TRACK_PWM;
      int ec = lineFL ? (int)(maxPwm * EDGE_STEER) : -(int)(maxPwm * EDGE_STEER);
      setMotors(
        constrain(base + (int)cor + ec, -maxPwm, maxPwm),
        constrain(base - (int)cor - ec, -maxPwm, maxPwm)
      );
      aiState = CHARGE;
      return;
    }

    if (lineR && !lineFL && !lineFR) {
      evadeDuration = EVADE_REAR_MS;
      evadeRear = true;
    } else {
      evadeDuration = EVADE_FRONT_MS;
      evadeRear = false;
      if (lineFL && !lineFR)       evadeDir = 1;
      else if (lineFR && !lineFL)  evadeDir = -1;
      else                         evadeDir = (random(2) == 0) ? 1 : -1;
    }
    evadeStart = now;
    aiState = EVADE;
    return;
  }

  // ========== SEARCH / TRACK / CHARGE / FLANK ==========
  if (!anyLaser) {
    aiState = SEARCH;
    flankDir = 0;
    int spd = maxPwm * SEARCH_PWM;
    setMotors(spd, -spd);
  } else {
    int minD = 9999;
    if (det0 && d0mm < minD) minD = d0mm;
    if (det1 && d1mm < minD) minD = d1mm;
    if (det2 && d2mm < minD) minD = d2mm;

    float err = eff1 - eff2;
    float cor = KP * err;

    if (minD > FLANK_THRESH) {
      aiState = FLANK;
      if (flankDir == 0) {
        if (det1 && !det2)       flankDir = -1;
        else if (det2 && !det1)  flankDir = 1;
        else                     flankDir = (random(2) == 0) ? 1 : -1;
      }
      float arcCor = KP * err + flankDir * FLANK_ANGLE * 150.0;
      int base = maxPwm * FLANK_PWM;
      setMotors(
        constrain(base + (int)arcCor, -maxPwm, maxPwm),
        constrain(base - (int)arcCor, -maxPwm, maxPwm)
      );
    } else {
      flankDir = 0;
      int base;
      if (minD < CHARGE_THRESH) { aiState = CHARGE; base = maxPwm * CHARGE_PWM; }
      else                      { aiState = TRACK;  base = maxPwm * TRACK_PWM;  }
      setMotors(
        constrain(base + (int)cor, -maxPwm, maxPwm),
        constrain(base - (int)cor, -maxPwm, maxPwm)
      );
    }
  }
}

// ===================== SETUP =====================
void setup() {
  // Moteurs
  pinMode(ENA, OUTPUT); pinMode(IN1, OUTPUT); pinMode(IN2, OUTPUT);
  pinMode(ENB, OUTPUT); pinMode(IN3, OUTPUT); pinMode(IN4, OUTPUT);
  stopMotors();

  // Capteurs ligne
  pinMode(LINE_FL, INPUT);
  pinMode(LINE_FR, INPUT);
  pinMode(LINE_R,  INPUT);

  // Bouton start + LED
  pinMode(BTN_START, INPUT_PULLUP);
  pinMode(LED_STATE, OUTPUT);

  Serial.begin(9600);
  Serial.println(F("SumoBot v1.0"));

  // I2C
  Wire.begin();
  Wire.setClock(400000);
  initLasers();

  // Init filtre median (remplir le buffer)
  for (int i = 0; i < 3; i++) {
    laserBuf0[i] = LASER_RANGE;
    laserBuf1[i] = LASER_RANGE;
    laserBuf2[i] = LASER_RANGE;
  }

  // Seed random
  randomSeed(analogRead(A5));

  // Watchdog 500ms — reset si le code bloque
  wdt_enable(WDTO_500MS);

  aiState = WAIT_START;
  Serial.println(F("En attente du bouton START..."));
}

// ===================== LOOP =====================
void loop() {
  unsigned long loopStart = micros();

  wdt_reset();

  // Attente bouton start
  if (aiState == WAIT_START) {
    updateLED();
    if (digitalRead(BTN_START) == LOW) {
      delay(50); // debounce
      if (digitalRead(BTN_START) == LOW) {
        countdownStart = millis();
        aiState = COUNTDOWN;
        Serial.println(F("COUNTDOWN 5s..."));
      }
    }
    return;
  }

  // Countdown
  if (aiState == COUNTDOWN) {
    updateLED();
    stopMotors();
    if (millis() - countdownStart >= COUNTDOWN_MS) {
      aiState = SEARCH;
      Serial.println(F("GO!"));
    }
    return;
  }

  // Lecture capteurs
  readSensors();

  // IA
  botAI();

  // Appliquer moteurs avec rampe
  updateMotors();

  // LED
  updateLED();

  // Cadencer la boucle a ~60Hz
  unsigned long elapsed = micros() - loopStart;
  if (elapsed < LOOP_PERIOD_US) {
    delayMicroseconds(LOOP_PERIOD_US - elapsed);
  }
}

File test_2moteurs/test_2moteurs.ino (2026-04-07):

// Test Phase 2 - Deux moteurs via L298N
// Moteur gauche : ENA=10 (PWM), IN1=9, IN2=8
// Moteur droit  : ENB=5  (PWM), IN3=6, IN4=7

#define ENA 10
#define IN1 9
#define IN2 8

#define ENB 5
#define IN3 6
#define IN4 7

void setup() {
  pinMode(ENA, OUTPUT);
  pinMode(IN1, OUTPUT);
  pinMode(IN2, OUTPUT);
  pinMode(ENB, OUTPUT);
  pinMode(IN3, OUTPUT);
  pinMode(IN4, OUTPUT);
  Serial.begin(9600);
  Serial.println("Test 2 moteurs - pret");
  delay(2000);
}

void moteurGauche(int vitesse, bool avant) {
  digitalWrite(IN1, avant ? HIGH : LOW);
  digitalWrite(IN2, avant ? LOW : HIGH);
  analogWrite(ENA, vitesse);
}

void moteurDroit(int vitesse, bool avant) {
  digitalWrite(IN3, avant ? HIGH : LOW);
  digitalWrite(IN4, avant ? LOW : HIGH);
  analogWrite(ENB, vitesse);
}

void stopMoteurs() {
  analogWrite(ENA, 0);
  analogWrite(ENB, 0);
  digitalWrite(IN1, LOW);
  digitalWrite(IN2, LOW);
  digitalWrite(IN3, LOW);
  digitalWrite(IN4, LOW);
}

void loop() {
  // Avancer tout droit
  Serial.println("Avancer");
  moteurGauche(180, true);
  moteurDroit(180, true);
  delay(2000);

  stopMoteurs();
  delay(1000);

  // Reculer
  Serial.println("Reculer");
  moteurGauche(180, false);
  moteurDroit(180, false);
  delay(2000);

  stopMoteurs();
  delay(1000);

  // Tourner a gauche (droit avance, gauche recule)
  Serial.println("Tourner gauche");
  moteurGauche(150, false);
  moteurDroit(150, true);
  delay(1500);

  stopMoteurs();
  delay(1000);

  // Tourner a droite (gauche avance, droit recule)
  Serial.println("Tourner droite");
  moteurGauche(150, true);
  moteurDroit(150, false);
  delay(1500);

  stopMoteurs();
  delay(1000);

  // Courbe douce a gauche (droit plus vite)
  Serial.println("Courbe gauche");
  moteurGauche(100, true);
  moteurDroit(200, true);
  delay(2000);

  stopMoteurs();
  delay(3000);

  Serial.println("--- Cycle termine ---");
}

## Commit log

2026-04-07 Initial commit: SumoBot project with simulation, Arduino tests, and AI memory
    Robot sumo Arduino Mega 2560 (500g-1kg category):
    - Simulation: visual (index.html), headless (headless.js), Monte Carlo optimizer
    - Arduino tests: motor, dual motor, line sensor, line+motor reaction
    - AI strategy memory: optimization results, physics model, hardware config
    - CLAUDE.md project documentation
2026-04-07 Add flanking/counter-dodge strategies, sensor-only constraint, enemy tuning UI
    - Implement 3 new bot AI strategies: FLANK (arc approach at >636mm),
    COUNTER (IMU-based frontal dodge), enhanced TILT_ESC (spin + reverse)
    - Optimize all params via Monte Carlo v3 (92.55% vs smart enemy, up from 70.4%)
    - Enforce sensor-only constraint: remove all position/heading cheats from botAI
    - Add enemy mass/speed/size sliders in visual sim (0.5x-4x range)
    - Fix manual control: full override without line sensor interference
    - Sync index.html with headless.js strategies and optimized params
    - Add montecarlo_v3 and v3_refine scripts for multi-profile optimization
    - Document sensor-only rule in CLAUDE.md
    Co-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
2026-04-08 Add project README and hardware assembly guide
    - README: simulation-first approach, Monte Carlo optimization, state machine, key findings
    - HARDWARE.md: complete wiring guide, step-by-step assembly, pinout reference
2026-04-08 Fix diagram layout: separate overlapping labels and wires
    - Alimentation: legend spacing fixed
    - Cablage: OUT labels moved to sides, I2C/XSHUT wires separated
    - Capteurs: TCRT labels on single line, laser labels spaced from TCRT
    - Pinout: more vertical space for all rows
2026-04-08 Fix robot diagram: 2 wheels only, blue color
    Robot has 2 wheels (left/right) + 1 caster ball, not 4 wheels.
    Changed wheel color to light blue to distinguish from motor boxes.
2026-04-08 Fix GND wires in alimentation diagram
    Each component now has its own GND wire to the common bar:
    LM2596, Arduino, L298N, Moteur G, Moteur D.
2026-04-12 Add MuJoCo 3D simulation system and update README
    Introduce second simulation stack based on MuJoCo for high-fidelity physics
    validation alongside the existing JS simulator. README now documents both
    systems and includes a preview GIF.
    [arena.xml, enemy.xml, scene.xml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]
